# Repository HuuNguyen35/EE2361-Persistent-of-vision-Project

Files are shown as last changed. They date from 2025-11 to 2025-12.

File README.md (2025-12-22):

# EE2361 Persistent-of-Vision (POV) Fan Display  
**EE2361 – Fall 2025 Final Project**

This project implements a **Persistent-of-Vision (POV) display** using a
**PIC24FJ64GA002 microcontroller**, a **DC motor–driven rotating fan**, and a
**WS2812B RGB LED strip** mounted on the fan blade. By synchronizing LED updates
with the fan’s rotation, the system creates the illusion of a stable image or
text in mid-air.

An **IR reflective sensor** measures the fan’s RPM, and an **HTML-based pattern
generator** allows users to design custom RGB patterns that are exported
directly into firmware-ready C arrays.

---

## Demo
https://screenpal.com/content/video/cTl336nY7Au

---

## Key Features
- PIC24FJ64GA002–based embedded control
- 28-LED WS2812B RGB LED strip mounted on a rotating fan blade
- IR sensor–based RPM measurement
- Optional LCD display for live RPM readout
- HTML pixel-art tool to generate POV patterns
- Custom mechanical chassis designed in SolidWorks
- Slip ring used to route power/signals to the rotating blade

---

## System Overview
1. A DC motor spins the fan blade with the LED strip attached.
2. An IR reflective sensor mounted beneath the fan detects each rotation.
3. The PIC24 measures the rotation period and calculates timing for each angular
   column.
4. LED colors are updated at precise times during the rotation.
5. Due to persistence of vision, the viewer perceives a stable image or text.

---

## Hardware
- **Microcontroller:** PIC24FJ64GA002  
- **LEDs:** WS2812B RGB LED strip (28 LEDs total)  
- **Sensor:** TCRT5000 IR reflective sensor module  
- **Motor:** DC motor  
- **Mechanical:**  
  - Custom chassis designed in SolidWorks  
  - Slip ring for rotating electrical connections  
- **Optional:** LCD display for RPM readout  

### Power
- **5 V:** WS2812B LED strip and DC motor  
- **3.3 V:** PIC24FJ64GA002 and IR sensor  
- Power is provided via the **Microchip SNAP board**

---

## Firmware
- **IDE:** MPLAB X  
- **Target MCU:** PIC24FJ64GA002  
- The repository includes a ready-to-build **`.X` MPLAB project**
- No special configuration bits or external libraries required

### Firmware Responsibilities
- Read IR sensor signals to determine rotation timing (RPM)
- Divide each rotation into fixed angular columns
- Output RGB data to the WS2812B LED strip
- Optionally update an LCD with real-time RPM values

---

## Pattern Generator (HTML Tool)
The project includes an HTML-based **circular pixel art generator** used to
design POV display patterns.

### Capabilities
- Paint RGB patterns on a polar grid (radial pixels × angular columns)
- Render text using a built-in 3×5 pixel font
- Export patterns in multiple formats

### Output
- **C source output for PIC24**, including:
  - Pattern dimensions
  - RGB array formatted for direct inclusion in firmware

### How to Use
1. Open the HTML file in a web browser.
2. Create a pattern or render text.
3. Click **Export C (PIC24)**.
4. Copy the generated output into:

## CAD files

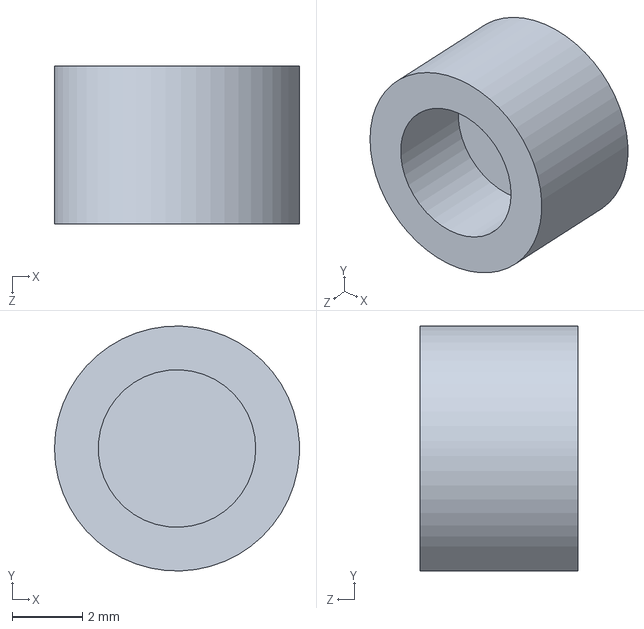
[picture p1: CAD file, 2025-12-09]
EE_2361_pillar_cap.SLDPRT
7.00 x 7.00 x 4.50 mm

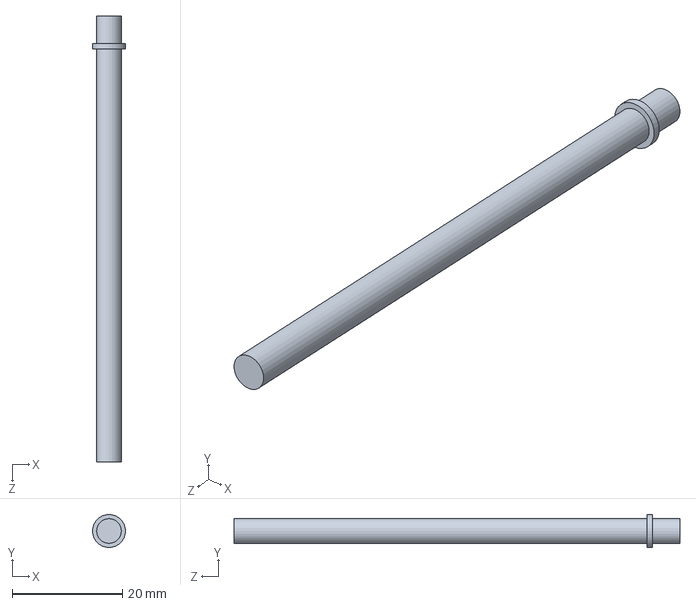
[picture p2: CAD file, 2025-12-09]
EE_2361_pillar.SLDPRT
6.00 x 6.00 x 81.0 mm

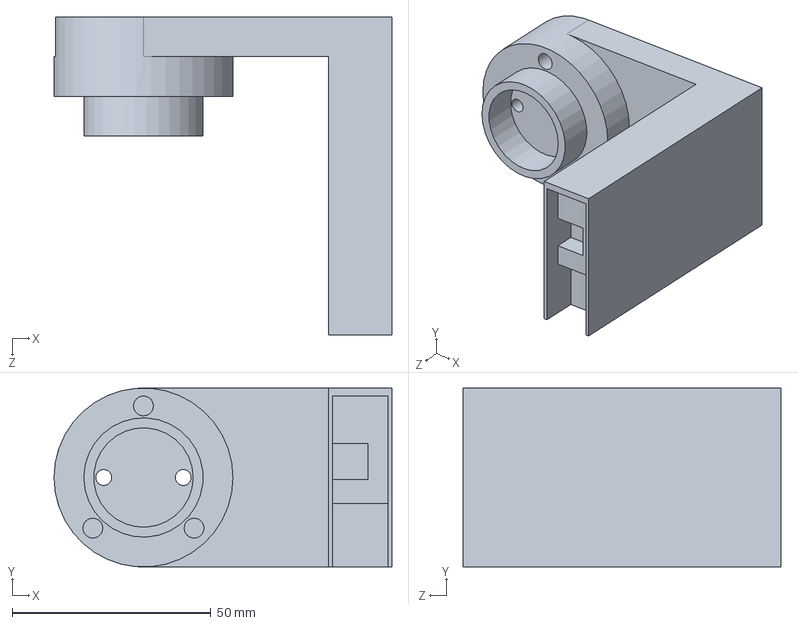
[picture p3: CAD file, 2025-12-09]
EE_2361_fan_holder.SLDPRT
85.0 x 45.0 x 80.0 mm

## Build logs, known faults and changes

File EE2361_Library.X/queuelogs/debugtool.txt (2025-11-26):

753 1764175239638 GEN4_CONNECT_DIAGNOSTICS:MPLABCommTool is NOT null
753 1764175239638 GEN4_CONNECT_DIAGNOSTICS:AttachedToolPID = 9018, AttachedToolVID = 4d8
753 1764175239638 GEN4_CONNECT_DIAGNOSTICS:transport type = USB
753 1764175239639 GEN4_CONNECT_DIAGNOSTICS:AttachedToolPID = 9018, AttachedToolVID = 4d8
753 1764175240054 com.microchip.mplab.mdbcore.RealICETool.RIDbgToolCom
753 1764175240054 GEN4_CONNECT_DIAGNOSTICS:Before MPLABCommTool.Connect()
753 1764175240054 GEN4_CONNECT_DIAGNOSTICS:After MPLABCommTool.Connect()
753 1764175240054 GEN4_CONNECT_DIAGNOSTICS:MPLABCommTool.Connect() returned MPLABCOMM_NO_ERROR
753 1764175240055 GEN4_CONNECT_DIAGNOSTICS:Attaching to MPLABCommTool plugnplay
753 1764175240091 GEN4_CONNECT_DIAGNOSTICS:Adding new plug and play observer com.microchip.mplab.mdbcore.RI4Tool.RI4ToolBase$RI4PlugNPlayObserver@9b9439
753 1764175240091 GEN4_CONNECT_DIAGNOSTICS:Begin PlugNPlayObservers list dump:
753 1764175240091 GEN4_CONNECT_DIAGNOSTICS:com.microchip.mplab.mdbcore.RI4Tool.RI4ToolBase$RI4PlugNPlayObserver@9b9439
753 1764175240091 GEN4_CONNECT_DIAGNOSTICS:End PlugNPlayObservers list dump:
753 1764175240111 GEN4_CONNECT_DIAGNOSTICS:Registering for alternate PNP notifications. CommPnPCriteria.cPIDList = [9019, 901c, 2180], CommPnPCriteria.cSerialNumber = 021038102ryn006859

753 1764175247402 GEN4_TO_CONTROLLER_LOG:GEN4_INIT_INT_LOG_PIC24FJ64GA002 Pre:init
753 1764175247402 GEN4_TO_CONTROLLER_LOG:GEN4_INIT_INT_LOG_PIC24FJ64GA002 Payload
753 1764175247402 GEN4_TO_CONTROLLER_LOG:GEN4_INIT_INT_LOG_PIC24FJ64GA002 DeviceInfo: Values:
753 1764175247402 GEN4_TO_CONTROLLER_LOG:GEN4_INIT_INT_LOG_PIC24FJ64GA002 DeviceInfo: pcAddress = 0000002e, Vpp = 3.25, useRowEraseIfVoltageIsLow = false, voltageBelowWhichUseRowErase = 0.00, deviceName = PIC24FJ64GA002, programmerType = PIC24FJ
753 1764175247402 GEN4_TO_CONTROLLER_LOG:GEN4_INIT_INT_LOG_PIC24FJ64GA002 DeviceInfo: MemInfo values:
753 1764175247404 GEN4_TO_CONTROLLER_LOG:GEN4_INIT_INT_LOG_PIC24FJ64GA002 DeviceInfo: mask = ffffff, exists = true, startAddr = 00000000, endAddr = 0000abfb, rowSize = 0400, rowEraseSize = 0400, addrInc = 0002, widthProgram = 0004
753 1764175247404 GEN4_TO_CONTROLLER_LOG:GEN4_INIT_INT_LOG_PIC24FJ64GA002 DeviceInfo: mask = ffff, exists = true, startAddr = 0000abfc, endAddr = 0000abff, rowSize = 0001, rowEraseSize = 0000, addrInc = 0002, widthProgram = 0002
753 1764175247404 GEN4_TO_CONTROLLER_LOG:GEN4_INIT_INT_LOG_PIC24FJ64GA002 DeviceInfo: mask = 0000, exists = false, startAddr = 00000000, endAddr = 00000000, rowSize = 0000, rowEraseSize = 0400, addrInc = 0000, widthProgram = 0000
753 1764175247404 GEN4_TO_CONTROLLER_LOG:GEN4_INIT_INT_LOG_PIC24FJ64GA002 DeviceInfo: mask = 0000, exists = false, startAddr = 00000000, endAddr = 00000000, rowSize = 0000, rowEraseSize = 0000, addrInc = 0000, widthProgram = 0000
753 1764175247404 GEN4_TO_CONTROLLER_LOG:GEN4_INIT_INT_LOG_PIC24FJ64GA002 DeviceInfo: mask = 0000, exists = false, startAddr = 00000000, endAddr = 00000000, rowSize = 0000, rowEraseSize = 0000, addrInc = 0000, widthProgram = 0000
753 1764175247404 GEN4_TO_CONTROLLER_LOG:GEN4_INIT_INT_LOG_PIC24FJ64GA002 DeviceInfo: mask = ffffff, exists = true, startAddr = 00800000, endAddr = 008007ff, rowSize = 0400, rowEraseSize = 0400, addrInc = 0002, widthProgram = 0004
753 1764175247404 GEN4_TO_CONTROLLER_LOG:GEN4_INIT_INT_LOG_PIC24FJ64GA002 DeviceInfo: mask = 0000, exists = false, startAddr = 00000000, endAddr = 00000000, rowSize = 0000, rowEraseSize = 0000, addrInc = 0002, widthProgram = 0002
753 1764175247404 GEN4_TO_CONTROLLER_LOG:GEN4_INIT_INT_LOG_PIC24FJ64GA002 DeviceInfo: mask = 0000, exists = false, startAddr = 00000000, endAddr = 00000000, rowSize = 0000, rowEraseSize = 0000, addrInc = 0000, widthProgram = 0000
753 1764175247404 GEN4_TO_CONTROLLER_LOG:GEN4_INIT_INT_LOG_PIC24FJ64GA002 DeviceInfo: mask = 0000, exists = false, startAddr = 00000000, endAddr = 00000000, rowSize = 0000, rowEraseSize = 0000, addrInc = 0000, widthProgram = 0000
753 1764175247404 GEN4_TO_CONTROLLER_LOG:GEN4_INIT_INT_LOG_PIC24FJ64GA002 DeviceInfo: mask = 0000, exists = false, startAddr = 00000000, endAddr = 00000000, rowSize = 0000, rowEraseSize = 0000, addrInc = 0000, widthProgram = 0000
753 1764175247404 GEN4_TO_CONTROLLER_LOG:GEN4_INIT_INT_LOG_PIC24FJ64GA002 DeviceInfo: mask = 0000, exists = false, startAddr = 00000000, endAddr = 00000000, rowSize = 0000, rowEraseSize = 0000, addrInc = 0002, widthProgram = 0002
753 1764175247404 GEN4_TO_CONTROLLER_LOG:GEN4_INIT_INT_LOG_PIC24FJ64GA002 DeviceInfo: mask = 0000, exists = false, startAddr = 00000000, endAddr = 00000000, rowSize = 0000, rowEraseSize = 0000, addrInc = 0000, widthProgram = 0000
753 1764175247404 GEN4_TO_CONTROLLER_LOG:GEN4_INIT_INT_LOG_PIC24FJ64GA002 DeviceInfo: mask = 0000, exists = false, startAddr = 00000000, endAddr = 00000000, rowSize = 0000, rowEraseSize = 0000, addrInc = 0000, widthProgram = 0000
753 1764175247404 GEN4_TO_CONTROLLER_LOG:GEN4_INIT_INT_LOG_PIC24FJ64GA002 DeviceInfo: mask = 0000, exists = false, startAddr = 00000000, endAddr = 00000000, rowSize = 0000, rowEraseSize = 0000, addrInc = 0000, widthProgram = 0000
753 1764175247404 GEN4_TO_CONTROLLER_LOG:GEN4_INIT_INT_LOG_PIC24FJ64GA002 DeviceInfo: mask = 0000, exists = false, startAddr = 00000000, endAddr = 00000000, rowSize = 0000, rowEraseSize = 0000, addrInc = 0000, widthProgram = 0000
753 1764175247404 GEN4_TO_CONTROLLER_LOG:GEN4_INIT_INT_LOG_PIC24FJ64GA002 DeviceInfo: mask = 0000, exists = false, startAddr = 00000000, endAddr = 00000000, rowSize = 0000, rowEraseSize = 0000, addrInc = 0000, widthProgram = 0000
753 1764175247404 GEN4_TO_CONTROLLER_LOG:GEN4_INIT_INT_LOG_PIC24FJ64GA002 DeviceInfo: mask = 7fffffff, exists = true, startAddr = 00ff0000, endAddr = 00ff0003, rowSize = 0001, rowEraseSize = 0000, addrInc = 0001, widthProgram = 0001
753 1764175247404 GEN4_TO_CONTROLLER_LOG:GEN4_INIT_INT_LOG_PIC24FJ64GA002 DeviceInfo: mask = 0000, exists = false, startAddr = 00000000, endAddr = 00000000, rowSize = 0000, rowEraseSize = 0000, addrInc = 0000, widthProgram = 0000
753 1764175247404 GEN4_TO_CONTROLLER_LOG:GEN4_INIT_INT_LOG_PIC24FJ64GA002 DeviceInfo: mask = 0000, exists = false, startAddr = 00000000, endAddr = 00000000, rowSize = 0000, rowEraseSize = 0000, addrInc = 0000, widthProgram = 0000
753 1764175247404 GEN4_TO_CONTROLLER_LOG:GEN4_INIT_INT_LOG_PIC24FJ64GA002 DeviceInfo: mask = 0000, exists = false, startAddr = 00000000, endAddr = 00000000, rowSize = 0000, rowEraseSize = 0000, addrInc = 0000, widthProgram = 0000
753 1764175247404 GEN4_TO_CONTROLLER_LOG:GEN4_INIT_INT_LOG_PIC24FJ64GA002 DeviceInfo: mask = 0000, exists = false, startAddr = 00000000, endAddr = 00000000, rowSize = 0000, rowEraseSize = 0000, addrInc = 0000, widthProgram = 0000
753 1764175247404 GEN4_TO_CONTROLLER_LOG:GEN4_INIT_INT_LOG_PIC24FJ64GA002 DeviceInfo: mask = 0000, exists = false, startAddr = 00000000, endAddr = 00000000, rowSize = 0000, rowEraseSize = 0000, addrInc = 0000, widthProgram = 0000
753 1764175247404 GEN4_TO_CONTROLLER_LOG:GEN4_INIT_INT_LOG_PIC24FJ64GA002 DeviceInfo: mask = 0000, exists = false, startAddr = 00000000, endAddr = 00000000, rowSize = 0000, rowEraseSize = 0000, addrInc = 0000, widthProgram = 0000
753 1764175247404 GEN4_TO_CONTROLLER_LOG:GEN4_INIT_INT_LOG_PIC24FJ64GA002 CfgRequiredBitsMask Values:
753 1764175247404 GEN4_TO_CONTROLLER_LOG:GEN4_INIT_INT_LOG_PIC24FJ64GA002 Address = 0000abfc, Mask = 0000fff7
753 1764175247404 GEN4_TO_CONTROLLER_LOG:GEN4_INIT_INT_LOG_PIC24FJ64GA002 Address = 0000abfe, Mask = 000077df
753 1764175247404 GEN4_TO_CONTROLLER_LOG:GEN4_INIT_INT_LOG_PIC24FJ64GA002 BasicInfo: Values:
753 1764175247404 GEN4_TO_CONTROLLER_LOG:GEN4_INIT_INT_LOG_PIC24FJ64GA002 Payload End
753 1764175250065 GEN4_TO_CONTROLLER_LOG:GEN4_INIT_INT_LOG_PIC24FJ64GA002 Post:init
753 1764175250065 GEN4_TO_CONTROLLER_LOG:GEN4_INIT_INT_LOG_PIC24FJ64GA002 Return Value
753 1764175250065 GEN4_TO_CONTROLLER_LOG:GEN4_INIT_INT_LOG_PIC24FJ64GA002 none
753 1764175250065 GEN4_TO_CONTROLLER_LOG:GEN4_INIT_INT_LOG_PIC24FJ64GA002 Return End

753 1764175250066 GEN4_TO_CONTROLLER_LOG:GEN4_INIT_INT_LOG_PIC24FJ64GA002 Pre:GetInterfaceProvider
753 1764175250066 GEN4_TO_CONTROLLER_LOG:GEN4_INIT_INT_LOG_PIC24FJ64GA002 Payload
753 1764175250066 GEN4_TO_CONTROLLER_LOG:GEN4_INIT_INT_LOG_PIC24FJ64GA002 RI4DebugInterface
753 1764175250066 GEN4_TO_CONTROLLER_LOG:GEN4_INIT_INT_LOG_PIC24FJ64GA002 Payload End
753 1764175250066 GEN4_TO_CONTROLLER_LOG:GEN4_INIT_INT_LOG_PIC24FJ64GA002 Post:GetInterfaceProvider
753 1764175250066 GEN4_TO_CONTROLLER_LOG:GEN4_INIT_INT_LOG_PIC24FJ64GA002 Return Value
753 1764175250066 GEN4_TO_CONTROLLER_LOG:GEN4_INIT_INT_LOG_PIC24FJ64GA002 com.microchip.mplab.libs.RI4ToolsController.implementations.RI4DebugInterfaceImpl@4d92831b
753 1764175250066 GEN4_TO_CONTROLLER_LOG:GEN4_INIT_INT_LOG_PIC24FJ64GA002 Return End

753 1764175250198 GEN4_TO_CONTROLLER_LOG:GEN4_INIT_INT_LOG_PIC24FJ64GA002 Pre:GetInterfaceProvider
753 1764175250198 GEN4_TO_CONTROLLER_LOG:GEN4_INIT_INT_LOG_PIC24FJ64GA002 Payload
753 1764175250198 GEN4_TO_CONTROLLER_LOG:GEN4_INIT_INT_LOG_PIC24FJ64GA002 RI4ProgramInterface
753 1764175250198 GEN4_TO_CONTROLLER_LOG:GEN4_INIT_INT_LOG_PIC24FJ64GA002 Payload End
753 1764175250198 GEN4_TO_CONTROLLER_LOG:GEN4_INIT_INT_LOG_PIC24FJ64GA002 Post:GetInterfaceProvider
753 1764175250198 GEN4_TO_CONTROLLER_LOG:GEN4_INIT_INT_LOG_PIC24FJ64GA002 Return Value
753 1764175250198 GEN4_TO_CONTROLLER_LOG:GEN4_INIT_INT_LOG_PIC24FJ64GA002 com.microchip.mplab.libs.RI4ToolsController.implementations.RI4ProgramInterfaceImpl@6d2c703d
753 1764175250198 GEN4_TO_CONTROLLER_LOG:GEN4_INIT_INT_LOG_PIC24FJ64GA002 Return End

753 1764175250281 GEN4_TO_CONTROLLER_LOG:GEN4_INIT_INT_LOG_PIC24FJ64GA002 Pre:GetInterfaceProvider
753 1764175250281 GEN4_TO_CONTROLLER_LOG:GEN4_INIT_INT_LOG_PIC24FJ64GA002 Payload
753 1764175250281 GEN4_TO_CONTROLLER_LOG:GEN4_INIT_INT_LOG_PIC24FJ64GA002 RI4ConnectInterface
753 1764175250281 GEN4_TO_CONTROLLER_LOG:GEN4_INIT_INT_LOG_PIC24FJ64GA002 Payload End
753 1764175250282 GEN4_TO_CONTROLLER_LOG:GEN4_INIT_INT_LOG_PIC24FJ64GA002 Post:GetInterfaceProvider
753 1764175250282 GEN4_TO_CONTROLLER_LOG:GEN4_INIT_INT_LOG_PIC24FJ64GA002 Return Value
753 1764175250282 GEN4_TO_CONTROLLER_LOG:GEN4_INIT_INT_LOG_PIC24FJ64GA002 com.microchip.mplab.libs.PK4ToolsController.PK4ConnectInterfaceImpl@3dc04ec9
753 1764175250282 GEN4_TO_CONTROLLER_LOG:GEN4_INIT_INT_LOG_PIC24FJ64GA002 Return End
753 1764175250329 GEN4_CONNECT_DIAGNOSTICS:acceptablePIDs = [9018, 9019, 901c]
753 1764175250329 GEN4_CONNECT_DIAGNOSTICS:otherPIDs = [2180]
753 1764175250329 GEN4_CONNECT_DIAGNOSTICS:Setting selected tool type to pk4
753 1764175250329 GEN4_CONNECT_DIAGNOSTICS:otherPIDs = [2180]
753 1764175250329 GEN4_CONNECT_DIAGNOSTICS:acceptablePIDs = [9018, 9019, 901c]

753 1764175250332 GEN4_TO_CONTROLLER_LOG:GEN4_CONNECT_INT_LOG_PIC24FJ64GA002 Pre:selectCore
753 1764175250332 GEN4_TO_CONTROLLER_LOG:GEN4_CONNECT_INT_LOG_PIC24FJ64GA002 Payload
753 1764175250332 GEN4_TO_CONTROLLER_LOG:GEN4_CONNECT_INT_LOG_PIC24FJ64GA002 PIC24FJ64GA002
753 1764175250332 GEN4_TO_CONTROLLER_LOG:GEN4_CONNECT_INT_LOG_PIC24FJ64GA002 Payload End
753 1764175250332 GEN4_TO_CONTROLLER_LOG:GEN4_CONNECT_INT_LOG_PIC24FJ64GA002 Post:selectCore
753 1764175250332 GEN4_TO_CONTROLLER_LOG:GEN4_CONNECT_INT_LOG_PIC24FJ64GA002 Return Value
753 1764175250332 GEN4_TO_CONTROLLER_LOG:GEN4_CONNECT_INT_LOG_PIC24FJ64GA002 none
753 1764175250332 GEN4_TO_CONTROLLER_LOG:GEN4_CONNECT_INT_LOG_PIC24FJ64GA002 Return End

753 1764175250332 GEN4_TO_CONTROLLER_LOG:GEN4_INIT_INT_LOG_PIC24FJ64GA002 Pre:GetInterfaceProvider
753 1764175250332 GEN4_TO_CONTROLLER_LOG:GEN4_INIT_INT_LOG_PIC24FJ64GA002 Payload
753 1764175250332 GEN4_TO_CONTROLLER_LOG:GEN4_INIT_INT_LOG_PIC24FJ64GA002 RI4ControllerDiagnosticsInterface
753 1764175250332 GEN4_TO_CONTROLLER_LOG:GEN4_INIT_INT_LOG_PIC24FJ64GA002 Payload End
753 1764175250332 GEN4_TO_CONTROLLER_LOG:GEN4_INIT_INT_LOG_PIC24FJ64GA002 Post:GetInterfaceProvider
753 1764175250332 GEN4_TO_CONTROLLER_LOG:GEN4_INIT_INT_LOG_PIC24FJ64GA002 Return Value
753 1764175250332 GEN4_TO_CONTROLLER_LOG:GEN4_INIT_INT_LOG_PIC24FJ64GA002 com.microchip.mplab.libs.RI4ToolsController.implementations.RI4ControllerDiagnosticsInterfaceImpl@4e9ac538
753 1764175250332 GEN4_TO_CONTROLLER_LOG:GEN4_INIT_INT_LOG_PIC24FJ64GA002 Return End

753 1764175250332 GEN4_TO_CONTROLLER_LOG:GEN4_INIT_INT_LOG_PIC24FJ64GA002 Pre:GetInterfaceProvider
753 1764175250332 GEN4_TO_CONTROLLER_LOG:GEN4_INIT_INT_LOG_PIC24FJ64GA002 Payload
753 1764175250332 GEN4_TO_CONTROLLER_LOG:GEN4_INIT_INT_LOG_PIC24FJ64GA002 ProgrammerToGo
753 1764175250332 GEN4_TO_CONTROLLER_LOG:GEN4_INIT_INT_LOG_PIC24FJ64GA002 Payload End
753 1764175250333 GEN4_TO_CONTROLLER_LOG:GEN4_INIT_INT_LOG_PIC24FJ64GA002 Post:GetInterfaceProvider
753 1764175250333 GEN4_TO_CONTROLLER_LOG:GEN4_INIT_INT_LOG_PIC24FJ64GA002 Return Value
753 1764175250333 GEN4_TO_CONTROLLER_LOG:GEN4_INIT_INT_LOG_PIC24FJ64GA002 com.microchip.mplab.libs.RI4ToolsController.implementations.ProgrammerToGoImpl@c42df67
753 1764175250333 GEN4_TO_CONTROLLER_LOG:GEN4_INIT_INT_LOG_PIC24FJ64GA002 Return End

753 1764175250334 GEN4_TO_CONTROLLER_LOG:GEN4_INIT_INT_LOG_PIC24FJ64GA002 Pre:GetInterfaceProvider
753 1764175250334 GEN4_TO_CONTROLLER_LOG:GEN4_INIT_INT_LOG_PIC24FJ64GA002 Payload
753 1764175250334 GEN4_TO_CONTROLLER_LOG:GEN4_INIT_INT_LOG_PIC24FJ64GA002 Status
753 1764175250334 GEN4_TO_CONTROLLER_LOG:GEN4_INIT_INT_LOG_PIC24FJ64GA002 Payload End
753 1764175250334 GEN4_TO_CONTROLLER_LOG:GEN4_INIT_INT_LOG_PIC24FJ64GA002 Post:GetInterfaceProvider
753 1764175250334 GEN4_TO_CONTROLLER_LOG:GEN4_INIT_INT_LOG_PIC24FJ64GA002 Return Value
753 1764175250334 GEN4_TO_CONTROLLER_LOG:GEN4_INIT_INT_LOG_PIC24FJ64GA002 null
753 1764175250334 GEN4_TO_CONTROLLER_LOG:GEN4_INIT_INT_LOG_PIC24FJ64GA002 Return End

753 1764175250352 GEN4_TO_CONTROLLER_LOG:GEN4_PROGRAM_INT_LOG_PIC24FJ64GA002 Pre:SetProgramExec
753 1764175250352 GEN4_TO_CONTROLLER_LOG:GEN4_PROGRAM_INT_LOG_PIC24FJ64GA002 Payload
753 1764175250354 GEN4_TO_CONTROLLER_LOG:GEN4_PROGRAM_INT_LOG_PIC24FJ64GA002 Test
753 1764175250354 GEN4_TO_CONTROLLER_LOG:GEN4_PROGRAM_INT_LOG_PIC24FJ64GA002 800000
753 1764175250354 GEN4_TO_CONTROLLER_LOG:GEN4_PROGRAM_INT_LOG_PIC24FJ64GA002 Length = 3054
753 1764175250354 GEN4_TO_CONTROLLER_LOG:GEN4_PROGRAM_INT_LOG_PIC24FJ64GA002 Payload End
753 1764175250355 GEN4_TO_CONTROLLER_LOG:GEN4_PROGRAM_INT_LOG_PIC24FJ64GA002 Post:SetProgramExec
753 1764175250355 GEN4_TO_CONTROLLER_LOG:GEN4_PROGRAM_INT_LOG_PIC24FJ64GA002 Return Value
753 1764175250355 GEN4_TO_CONTROLLER_LOG:GEN4_PROGRAM_INT_LOG_PIC24FJ64GA002 true
753 1764175250355 GEN4_TO_CONTROLLER_LOG:GEN4_PROGRAM_INT_LOG_PIC24FJ64GA002 Return End
753 1764175250355 GEN4_CONNECT_DIAGNOSTICS:ENTERING: com.microchip.mplab.mdbcore.RI4Tool.ConnectionHandler.CheckForFWUpdates()
753 1764175250355 GEN4_CONNECT_DIAGNOSTICS:Created FirmwareUpdateHandler com.microchip.mplab.mdbcore.pk4hybrid.pk4hybridFirmwareUpdateHandler@5181b78c
753 1764175250355 GEN4_CONNECT_DIAGNOSTICS:ENTERING: com.microchip.mplab.mdbcore.pk4hybrid.pk4hybridFirmwareUpdateHandler.UpdateFirmware(FirmwareInfo, UpdateMessage)
753 1764175250358 GEN4_CONNECT_DIAGNOSTICS:areWeInBoot returned false
753 1764175250358 GEN4_CONNECT_DIAGNOSTICS:inBoot = false
753 1764175250358 GEN4_CONNECT_DIAGNOSTICS:uMode = checkingVersions
753 1764175250358 GEN4_CONNECT_DIAGNOSTICS:selectedTool = pk4
753 1764175250358 GEN4_CONNECT_DIAGNOSTICS:current toolType = pk4
753 1764175250358 GEN4_CONNECT_DIAGNOSTICS:current tool mode = pk4
753 1764175250358 GEN4_CONNECT_DIAGNOSTICS:ENTERING: com.microchip.mplab.mdbcore.pk4hybrid.pk4hybridFirmwareUpdateHandler.GetUpdateInfo()
753 1764175250415 GEN4_CONNECT_DIAGNOSTICS:Parsing file  for firmware updates
753 1764175250415 GEN4_CONNECT_DIAGNOSTICS:ENTERING: com.microchip.mplab.mdbcore.pk4hybrid.pk4hybridFirmwareUpdateHandler.ParseSelectedVersionsFromJamFile()
753 1764175250415 GEN4_CONNECT_DIAGNOSTICS:Jame file line = snap_boot.hex,010155
753 1764175250415 GEN4_CONNECT_DIAGNOSTICS:Jame file line = scripts.xml,000891
753 1764175250415 GEN4_CONNECT_DIAGNOSTICS:Jame file line = snap_app1 020338, 0040C000
753 1764175250415 GEN4_CONNECT_DIAGNOSTICS:Jame file line = snap_app2 1.11.20, 00500000
753 1764175250415 GEN4_CONNECT_DIAGNOSTICS:Jame file line = snap_app3 000000, FFFFFFFF
753 1764175250415 GEN4_CONNECT_DIAGNOSTICS:Jame file line = snap_app4 000000, FFFFFFFF
753 1764175250415 GEN4_CONNECT_DIAGNOSTICS:Jame file line = snap_app5 000000, FFFFFFFF
753 1764175250415 GEN4_CONNECT_DIAGNOSTICS:Jame file line = snap_app6 000000, FFFFFFFF
753 1764175250415 GEN4_CONNECT_DIAGNOSTICS:Jame file line = snap_app7 000000, FFFFFFFF
753 1764175250415 GEN4_CONNECT_DIAGNOSTICS:Jame file line = snap_app8 000000, FFFFFFFF
753 1764175250415 GEN4_CONNECT_DIAGNOSTICS:EXITING: com.microchip.mplab.mdbcore.pk4hybrid.pk4hybridFirmwareUpdateHandler.ri4ParseSelectedVersionsFromJamFile()
753 1764175250415 GEN4_CONNECT_DIAGNOSTICS:EXITING: com.microchip.mplab.mdbcore.pk4hybrid.pk4hybridFirmwareUpdateHandler.GetUpdateInfo()
753 1764175250415 GEN4_CONNECT_DIAGNOSTICS:current toolType = pk4

753 1764175250415 GEN4_TO_CONTROLLER_LOG:GEN4_CONNECT_INT_LOG_PIC24FJ64GA002 Pre:EstablishCommunincations
753 1764175250415 GEN4_TO_CONTROLLER_LOG:GEN4_CONNECT_INT_LOG_PIC24FJ64GA002 Payload
753 1764175250415 GEN4_TO_CONTROLLER_LOG:GEN4_CONNECT_INT_LOG_PIC24FJ64GA002 com.microchip.mplab.mdbcore.PK4Tool.PK4Com@91e7ac0
753 1764175250415 GEN4_TO_CONTROLLER_LOG:GEN4_CONNECT_INT_LOG_PIC24FJ64GA002 Payload End
753 1764175250423 GEN4_TO_CONTROLLER_LOG:GEN4_CONNECT_INT_LOG_PIC24FJ64GA002 Post:EstablishCommunincations
753 1764175250423 GEN4_TO_CONTROLLER_LOG:GEN4_CONNECT_INT_LOG_PIC24FJ64GA002 Return Value
753 1764175250423 GEN4_TO_CONTROLLER_LOG:GEN4_CONNECT_INT_LOG_PIC24FJ64GA002 true
753 1764175250423 GEN4_TO_CONTROLLER_LOG:GEN4_CONNECT_INT_LOG_PIC24FJ64GA002 Return End

753 1764175250423 GEN4_TO_CONTROLLER_LOG:GEN4_CONNECT_INT_LOG_PIC24FJ64GA002 Pre:GetFirmwareInfo
753 1764175250423 GEN4_TO_CONTROLLER_LOG:GEN4_CONNECT_INT_LOG_PIC24FJ64GA002 Payload
753 1764175250423 GEN4_TO_CONTROLLER_LOG:GEN4_CONNECT_INT_LOG_PIC24FJ64GA002 null
753 1764175250423 GEN4_TO_CONTROLLER_LOG:GEN4_CONNECT_INT_LOG_PIC24FJ64GA002 Payload End
753 1764175250433 GEN4_TO_CONTROLLER_LOG:GEN4_CONNECT_INT_LOG_PIC24FJ64GA002 Post:GetFirmwareInfo
753 1764175250433 GEN4_TO_CONTROLLER_LOG:GEN4_CONNECT_INT_LOG_PIC24FJ64GA002 Return Value
753 1764175250433 GEN4_TO_CONTROLLER_LOG:GEN4_CONNECT_INT_LOG_PIC24FJ64GA002 FirmwareInfo: Values:
753 1764175250434 GEN4_TO_CONTROLLER_LOG:GEN4_CONNECT_INT_LOG_PIC24FJ64GA002 FirmwareInfo: boot = false, bootVer = 01.01.55, apVer = 02.03.38, fpgaVer = ff.ff.ff, scriptVer = 00.08.91, macAddress = 0495683578451535052485353485350, devID = a1020e01, devID1 = 1, devSN0 = ffffffff, devSN1 = ffffffff, serialNumber = 021038102RYN006859, appCommitID = null, scriptCommitID = 0674c1b56b, PCB_ID = 2
753 1764175250434 GEN4_TO_CONTROLLER_LOG:GEN4_CONNECT_INT_LOG_PIC24FJ64GA002 Return End
753 1764175250439 GEN4_CONNECT_DIAGNOSTICS:appNeedsUpdate returned false
753 1764175250439 GEN4_CONNECT_DIAGNOSTICS:EXITING: com.microchip.mplab.mdbcore.RI4Tool.ConnectionHandler.CheckForFWUpdates()

753 1764175250440 GEN4_TO_CONTROLLER_LOG:GEN4_CONNECT_INT_LOG_PIC24FJ64GA002 Pre:EstablishCommunincations
753 1764175250440 GEN4_TO_CONTROLLER_LOG:GEN4_CONNECT_INT_LOG_PIC24FJ64GA002 Payload
753 1764175250440 GEN4_TO_CONTROLLER_LOG:GEN4_CONNECT_INT_LOG_PIC24FJ64GA002 com.microchip.mplab.mdbcore.PK4Tool.PK4Com@91e7ac0
753 1764175250440 GEN4_TO_CONTROLLER_LOG:GEN4_CONNECT_INT_LOG_PIC24FJ64GA002 Payload End
753 1764175250440 GEN4_TO_CONTROLLER_LOG:GEN4_CONNECT_INT_LOG_PIC24FJ64GA002 Post:EstablishCommunincations
753 1764175250440 GEN4_TO_CONTROLLER_LOG:GEN4_CONNECT_INT_LOG_PIC24FJ64GA002 Return Value
753 1764175250440 GEN4_TO_CONTROLLER_LOG:GEN4_CONNECT_INT_LOG_PIC24FJ64GA002 true
753 1764175250440 GEN4_TO_CONTROLLER_LOG:GEN4_CONNECT_INT_LOG_PIC24FJ64GA002 Return End

753 1764175250440 GEN4_TO_CONTROLLER_LOG:GEN4_CONNECT_INT_LOG_PIC24FJ64GA002 Pre:GetFirmwareInfo
753 1764175250440 GEN4_TO_CONTROLLER_LOG:GEN4_CONNECT_INT_LOG_PIC24FJ64GA002 Payload
753 1764175250440 GEN4_TO_CONTROLLER_LOG:GEN4_CONNECT_INT_LOG_PIC24FJ64GA002 null
753 1764175250440 GEN4_TO_CONTROLLER_LOG:GEN4_CONNECT_INT_LOG_PIC24FJ64GA002 Payload End
753 1764175250448 GEN4_TO_CONTROLLER_LOG:GEN4_CONNECT_INT_LOG_PIC24FJ64GA002 Post:GetFirmwareInfo
753 1764175250448 GEN4_TO_CONTROLLER_LOG:GEN4_CONNECT_INT_LOG_PIC24FJ64GA002 Return Value
753 1764175250448 GEN4_TO_CONTROLLER_LOG:GEN4_CONNECT_INT_LOG_PIC24FJ64GA002 FirmwareInfo: Values:
753 1764175250448 GEN4_TO_CONTROLLER_LOG:GEN4_CONNECT_INT_LOG_PIC24FJ64GA002 FirmwareInfo: boot = false, bootVer = 01.01.55, apVer = 02.03.38, fpgaVer = ff.ff.ff, scriptVer = 00.08.91, macAddress = 0495683578451535052485353485350, devID = a1020e01, devID1 = 1, devSN0 = ffffffff, devSN1 = ffffffff, serialNumber = 021038102RYN006859, appCommitID = null, scriptCommitID = 0674c1b56b, PCB_ID = 2
753 1764175250448 GEN4_TO_CONTROLLER_LOG:GEN4_CONNECT_INT_LOG_PIC24FJ64GA002 Return End

753 1764175250449 GEN4_TO_CONTROLLER_LOG:GEN4_CONNECT_INT_LOG_PIC24FJ64GA002 Pre:GetFirmwareInfo
753 1764175250449 GEN4_TO_CONTROLLER_LOG:GEN4_CONNECT_INT_LOG_PIC24FJ64GA002 Payload
753 1764175250449 GEN4_TO_CONTROLLER_LOG:GEN4_CONNECT_INT_LOG_PIC24FJ64GA002 null
753 1764175250449 GEN4_TO_CONTROLLER_LOG:GEN4_CONNECT_INT_LOG_PIC24FJ64GA002 Payload End
753 1764175250456 GEN4_TO_CONTROLLER_LOG:GEN4_CONNECT_INT_LOG_PIC24FJ64GA002 Post:GetFirmwareInfo
753 1764175250456 GEN4_TO_CONTROLLER_LOG:GEN4_CONNECT_INT_LOG_PIC24FJ64GA002 Return Value
753 1764175250456 GEN4_TO_CONTROLLER_LOG:GEN4_CONNECT_INT_LOG_PIC24FJ64GA002 FirmwareInfo: Values:
753 1764175250456 GEN4_TO_CONTROLLER_LOG:GEN4_CONNECT_INT_LOG_PIC24FJ64GA002 FirmwareInfo: boot = false, bootVer = 01.01.55, apVer = 02.03.38, fpgaVer = ff.ff.ff, scriptVer = 00.08.91, macAddress = 0495683578451535052485353485350, devID = a1020e01, devID1 = 1, devSN0 = ffffffff, devSN1 = ffffffff, serialNumber = 021038102RYN006859, appCommitID = null, scriptCommitID = 0674c1b56b, PCB_ID = 2
753 1764175250456 GEN4_TO_CONTROLLER_LOG:GEN4_CONNECT_INT_LOG_PIC24FJ64GA002 Return End
753 1764175250459 GEN4_CONNECT_DIAGNOSTICS:ENTERING: com.microchip.mplab.mdbcore.RI4Tool.ConnectionHandler.CheckForFWUpdates()
753 1764175250459 GEN4_CONNECT_DIAGNOSTICS:Created FirmwareUpdateHandler com.microchip.mplab.mdbcore.pk4hybrid.pk4hybridFirmwareUpdateHandler@5181b78c
753 1764175250459 GEN4_CONNECT_DIAGNOSTICS:ENTERING: com.microchip.mplab.mdbcore.pk4hybrid.pk4hybridFirmwareUpdateHandler.UpdateFirmware(FirmwareInfo, UpdateMessage)
753 1764175250459 GEN4_CONNECT_DIAGNOSTICS:areWeInBoot returned false
753 1764175250459 GEN4_CONNECT_DIAGNOSTICS:inBoot = false
753 1764175250459 GEN4_CONNECT_DIAGNOSTICS:uMode = done
753 1764175250459 GEN4_CONNECT_DIAGNOSTICS:selectedTool = pk4
753 1764175250459 GEN4_CONNECT_DIAGNOSTICS:current toolType = pk4
753 1764175250459 GEN4_CONNECT_DIAGNOSTICS:current tool mode = pk4
753 1764175250459 GEN4_CONNECT_DIAGNOSTICS:ENTERING: com.microchip.mplab.mdbcore.pk4hybrid.pk4hybridFirmwareUpdateHandler.updatePk4HybridFirmware()
753 1764175250459 GEN4_CONNECT_DIAGNOSTICS:Don't upgrade fimware = false
753 1764175250459 GEN4_CONNECT_DIAGNOSTICS:ENTERING: com.microchip.mplab.mdbcore.pk4hybrid.pk4hybridFirmwareUpdateHandler.updatePk4HybridFirmware()
753 1764175250459 GEN4_CONNECT_DIAGNOSTICS:EXITING: com.microchip.mplab.mdbcore.pk4hybrid.pk4hybridFirmwareUpdateHandler.UpdateFirmware(FirmwareInfo, UpdateMessage)
753 1764175250459 GEN4_CONNECT_DIAGNOSTICS:EXITING: com.microchip.mplab.mdbcore.RI4Tool.ConnectionHandler.CheckForFWUpdates()

753 1764175250460 GEN4_TO_CONTROLLER_LOG:GEN4_CONNECT_INT_LOG_PIC24FJ64GA002 Pre:SetPowerInfo
753 1764175250460 GEN4_TO_CONTROLLER_LOG:GEN4_CONNECT_INT_LOG_PIC24FJ64GA002 Payload
753 1764175250460 GEN4_TO_CONTROLLER_LOG:GEN4_CONNECT_INT_LOG_PIC24FJ64GA002 PowerInfo: Values:
753 1764175250460 GEN4_TO_CONTROLLER_LOG:GEN4_CONNECT_INT_LOG_PIC24FJ64GA002 PowerInfo: shotDownSystem = false, isToolPower = false, voltage = 3.300000, useVppFirst = false, useLowVoltageProgramming = true, useMaintainActivePower = false
753 1764175250460 GEN4_TO_CONTROLLER_LOG:GEN4_CONNECT_INT_LOG_PIC24FJ64GA002 Payload End
753 1764175250460 XXXX 1764175250460, Thread 753: XXXX 1764175250460, Entering Thread 753: Commands::runScriptBasic with script contents. contents[0] = 0x39, ...  
753 1764175250464 XXXX 1764175250464, Thread 753: XXXX 1764175250464, Exiting Thread 753: Commands::runScriptBasic  
753 1764175250464 XXXX 1764175250464, Thread 753: XXXX 1764175250464, Entering Thread 753: Commands::runScriptBasic with script contents. contents[0] = 0x46, ...  
753 1764175250464 XXXX 1764175250464, Thread 753: XXXX 1764175250464, Exiting Thread 753: Commands::runScriptBasic  
753 1764175250464 XXXX 1764175250464, Thread 753: XXXX 1764175250464, Entering Thread 753: Commands::runScriptBasic with script contents. contents[0] = 0x44, ...  
753 1764175250465 XXXX 1764175250465, Thread 753: XXXX 1764175250465, Exiting Thread 753: Commands::runScriptBasic  
753 1764175250465 XXXX 1764175250465, Thread 753: XXXX 1764175250465, Entering Thread 753: Commands::runScriptBasic with script contents. contents[0] = 0xef, ...  
753 1764175250466 XXXX 1764175250466, Thread 753: XXXX 1764175250466, Exiting Thread 753: Commands::runScriptBasic  
753 1764175250466 XXXX 1764175250466, Thread 753: XXXX 1764175250466, Entering Thread 753: Commands::runScriptBasic with script contents. contents[0] = 0x40, ...  
753 1764175250467 XXXX 1764175250467, Thread 753: XXXX 1764175250467, Exiting Thread 753: Commands::runScriptBasic  
753 1764175250467 XXXX 1764175250467, Thread 753: XXXX 1764175250467, Entering Thread 753: Commands::runScriptBasic with script contents. contents[0] = 0x47, ...  
753 1764175250468 XXXX 1764175250468, Thread 753: XXXX 1764175250468, Exiting Thread 753: Commands::runScriptBasic  
753 1764175250468 GEN4_TO_CONTROLLER_LOG:GEN4_CONNECT_INT_LOG_PIC24FJ64GA002 Post:SetPowerInfo
753 1764175250468 GEN4_TO_CONTROLLER_LOG:GEN4_CONNECT_INT_LOG_PIC24FJ64GA002 Return Value
753 1764175250468 GEN4_TO_CONTROLLER_LOG:GEN4_CONNECT_INT_LOG_PIC24FJ64GA002 none
753 1764175250468 GEN4_TO_CONTROLLER_LOG:GEN4_CONNECT_INT_LOG_PIC24FJ64GA002 Return End

753 1764175250468 GEN4_TO_CONTROLLER_LOG:GEN4_CONNECT_INT_LOG_PIC24FJ64GA002 Pre:GetVoltageInfo
753 1764175250468 GEN4_TO_CONTROLLER_LOG:GEN4_CONNECT_INT_LOG_PIC24FJ64GA002 Payload
753 1764175250468 GEN4_TO_CONTROLLER_LOG:GEN4_CONNECT_INT_LOG_PIC24FJ64GA002 null
753 1764175250468 GEN4_TO_CONTROLLER_LOG:GEN4_CONNECT_INT_LOG_PIC24FJ64GA002 Payload End
753 1764175250468 XXXX 1764175250468, Thread 753: XXXX 1764175250468, Entering Thread 753: Commands::runScriptBasic with script contents. contents[0] = 0x47, ...  
753 1764175250469 XXXX 1764175250469, Thread 753: XXXX 1764175250469, Exiting Thread 753: Commands::runScriptBasic  
753 1764175250469 GEN4_TO_CONTROLLER_LOG:GEN4_CONNECT_INT_LOG_PIC24FJ64GA002 Post:GetVoltageInfo
753 1764175250469 GEN4_TO_CONTROLLER_LOG:GEN4_CONNECT_INT_LOG_PIC24FJ64GA002 Return Value
753 1764175250469 GEN4_TO_CONTROLLER_LOG:GEN4_CONNECT_INT_LOG_PIC24FJ64GA002 VoltagesInfo: Values:
753 1764175250469 GEN4_TO_CONTROLLER_LOG:GEN4_CONNECT_INT_LOG_PIC24FJ64GA002 VoltagesInfo: internalVdd = 3300, internalVpp = 3300, targetVdd = 3300, targetVpp = 3300, vddSense = 3300, temp = 25000, vddCurrentSense = 0, vddVoltageSense = 3300
753 1764175250469 GEN4_TO_CONTROLLER_LOG:GEN4_CONNECT_INT_LOG_PIC24FJ64GA002 Return End

753 1764175250469 GEN4_TO_CONTROLLER_LOG:GEN4_CONNECT_INT_LOG_PIC24FJ64GA002 Pre:GetFirmwareInfo
753 1764175250469 GEN4_TO_CONTROLLER_LOG:GEN4_CONNECT_INT_LOG_PIC24FJ64GA002 Payload
753 1764175250469 GEN4_TO_CONTROLLER_LOG:GEN4_CONNECT_INT_LOG_PIC24FJ64GA002 null
753 1764175250469 GEN4_TO_CONTROLLER_LOG:GEN4_CONNECT_INT_LOG_PIC24FJ64GA002 Payload End
753 1764175250477 GEN4_TO_CONTROLLER_LOG:GEN4_CONNECT_INT_LOG_PIC24FJ64GA002 Post:GetFirmwareInfo
753 1764175250477 GEN4_TO_CONTROLLER_LOG:GEN4_CONNECT_INT_LOG_PIC24FJ64GA002 Return Value
753 1764175250477 GEN4_TO_CONTROLLER_LOG:GEN4_CONNECT_INT_LOG_PIC24FJ64GA002 FirmwareInfo: Values:
753 1764175250477 GEN4_TO_CONTROLLER_LOG:GEN4_CONNECT_INT_LOG_PIC24FJ64GA002 FirmwareInfo: boot = false, bootVer = 01.01.55, apVer = 02.03.38, fpgaVer = ff.ff.ff, scriptVer = 00.08.91, macAddress = 0495683578451535052485353485350, devID = a1020e01, devID1 = 1, devSN0 = ffffffff, devSN1 = ffffffff, serialNumber = 021038102RYN006859, appCommitID = null, scriptCommitID = 0674c1b56b, PCB_ID = 2
753 1764175250477 GEN4_TO_CONTROLLER_LOG:GEN4_CONNECT_INT_LOG_PIC24FJ64GA002 Return End

753 1764175250477 GEN4_TO_CONTROLLER_LOG:GEN4_CONNECT_INT_LOG_PIC24FJ64GA002 Pre:SetToolInfo
753 1764175250477 GEN4_TO_CONTROLLER_LOG:GEN4_CONNECT_INT_LOG_PIC24FJ64GA002 Payload
753 1764175250477 GEN4_TO_CONTROLLER_LOG:GEN4_CONNECT_INT_LOG_PIC24FJ64GA002 ToolInfo: Values:
753 1764175250477 GEN4_TO_CONTROLLER_LOG:GEN4_CONNECT_INT_LOG_PIC24FJ64GA002 ToolInfo: speedLevel = 1, PGCResistance = 4700, PGDResistance = 4700, PGCPullDir = PullDown, PGDPullDir = PullDown, ICSPSelected = Wire2
753 1764175250477 GEN4_TO_CONTROLLER_LOG:GEN4_CONNECT_INT_LOG_PIC24FJ64GA002 Payload End
753 1764175250477 XXXX 1764175250477, Thread 753: XXXX 1764175250477, Entering Thread 753: Commands::runScriptBasic with script contents. contents[0] = 0x27, ...  
753 1764175250478 XXXX 1764175250478, Thread 753: XXXX 1764175250478, Exiting Thread 753: Commands::runScriptBasic  
753 1764175250478 XXXX 1764175250478, Thread 753: XXXX 1764175250478, Entering Thread 753: Commands::runScriptBasic, script name = SetSpeedFromDevice, timeOut = -1 ms  
753 1764175250479 XXXX 1764175250479, Thread 753: XXXX 1764175250479, Exiting Thread 753: Commands::runScriptBasic  
753 1764175250479 XXXX 1764175250479, Thread 753: XXXX 1764175250479, Entering Thread 753: Commands::runScriptBasic with script contents. contents[0] = 0xed, ...  
753 1764175250480 XXXX 1764175250480, Thread 753: XXXX 1764175250480, Exiting Thread 753: Commands::runScriptBasic  
753 1764175250480 XXXX 1764175250480, Thread 753: XXXX 1764175250480, Entering Thread 753: Commands::runScriptBasic with script contents. contents[0] = 0xec, ...  
753 1764175250481 XXXX 1764175250481, Thread 753: XXXX 1764175250481, Exiting Thread 753: Commands::runScriptBasic  
753 1764175250481 XXXX 1764175250481, Thread 753: XXXX 1764175250481, Entering Thread 753: Commands::runScriptBasic with script contents. contents[0] = 0xd4, ...  
753 1764175250482 XXXX 1764175250482, Thread 753: XXXX 1764175250482, Exiting Thread 753: Commands::runScriptBasic  
753 1764175250482 XXXX 1764175250482, Thread 753: XXXX 1764175250482, Entering Thread 753: Commands::runScriptBasic with script contents. contents[0] = 0xcd, ...  
753 1764175250483 XXXX 1764175250483, Thread 753: XXXX 1764175250483, Exiting Thread 753: Commands::runScriptBasic  
753 1764175250483 XXXX 1764175250483, Thread 753: XXXX 1764175250483, Entering Thread 753: Commands::runScriptBasic with script contents. contents[0] = 0xce, ...  
753 1764175250484 XXXX 1764175250484, Thread 753: XXXX 1764175250484, Exiting Thread 753: Commands::runScriptBasic  
753 1764175250484 XXXX 1764175250484, Thread 753: XXXX 1764175250484, Entering Thread 753: Commands::runScriptBasic with script contents. contents[0] = 0xcd, ...  
753 1764175250485 XXXX 1764175250485, Thread 753: XXXX 1764175250485, Exiting Thread 753: Commands::runScriptBasic  
753 1764175250485 XXXX 1764175250485, Thread 753: XXXX 1764175250485, Entering Thread 753: Commands::runScriptBasic with script contents. contents[0] = 0xce, ...  
753 1764175250486 XXXX 1764175250486, Thread 753: XXXX 1764175250486, Exiting Thread 753: Commands::runScriptBasic  
753 1764175250486 GEN4_TO_CONTROLLER_LOG:GEN4_CONNECT_INT_LOG_PIC24FJ64GA002 Post:SetToolInfo
753 1764175250486 GEN4_TO_CONTROLLER_LOG:GEN4_CONNECT_INT_LOG_PIC24FJ64GA002 Return Value
753 1764175250486 GEN4_TO_CONTROLLER_LOG:GEN4_CONNECT_INT_LOG_PIC24FJ64GA002 none
753 1764175250486 GEN4_TO_CONTROLLER_LOG:GEN4_CONNECT_INT_LOG_PIC24FJ64GA002 Return End

753 1764175250487 GEN4_TO_CONTROLLER_LOG:GEN4_CONNECT_INT_LOG_PIC24FJ64GA002 Pre:GetTargetIDInfo
753 1764175250487 GEN4_TO_CONTROLLER_LOG:GEN4_CONNECT_INT_LOG_PIC24FJ64GA002 Payload
753 1764175250487 GEN4_TO_CONTROLLER_LOG:GEN4_CONNECT_INT_LOG_PIC24FJ64GA002 null
753 1764175250487 GEN4_TO_CONTROLLER_LOG:GEN4_CONNECT_INT_LOG_PIC24FJ64GA002 Payload End
753 1764175250489 XXXX 1764175250489, Thread 753: XXXX 1764175250489, Entering Thread 753: Commands::runScriptBasic, script name = SetSpeedFromDevice, timeOut = -1 ms  
753 1764175250490 XXXX 1764175250490, Thread 753: XXXX 1764175250490, Exiting Thread 753: Commands::runScriptBasic  
753 1764175250490 XXXX 1764175250490, Thread 753: XXXX 1764175250490, Entering Thread 753: Commands::runScriptBasic with script contents. contents[0] = 0xed, ...  
753 1764175250491 XXXX 1764175250491, Thread 753: XXXX 1764175250491, Exiting Thread 753: Commands::runScriptBasic  
753 1764175250491 XXXX 1764175250491, Thread 753: XXXX 1764175250491, Entering Thread 753: Commands::runScriptBasic with script contents. contents[0] = 0xec, ...  
753 1764175250492 XXXX 1764175250492, Thread 753: XXXX 1764175250492, Exiting Thread 753: Commands::runScriptBasic  
753 1764175250492 XXXX 1764175250492, Thread 753: XXXX 1764175250492, Entering Thread 753: Commands::runScriptBasic, script name = EnterTMOD_LV, timeOut = -1 ms  
753 1764175250520 XXXX 1764175250520, Thread 753: XXXX 1764175250520, Exiting Thread 753: Commands::runScriptBasic  
753 1764175250520 XXXX 1764175250520, Thread 753: XXXX 1764175250520, Entering Thread 753: Commands::runScriptBasic, script name = GetDeviceID, timeOut = -1 ms  
753 1764175250522 XXXX 1764175250522, Thread 753: XXXX 1764175250522, Exiting Thread 753: Commands::runScriptBasic  
753 1764175250522 GEN4_TO_CONTROLLER_LOG:GEN4_CONNECT_INT_LOG_PIC24FJ64GA002 Post:GetTargetIDInfo
753 1764175250522 GEN4_TO_CONTROLLER_LOG:GEN4_CONNECT_INT_LOG_PIC24FJ64GA002 Return Value
753 1764175250522 GEN4_TO_CONTROLLER_LOG:GEN4_CONNECT_INT_LOG_PIC24FJ64GA002 TargetIDInfo: Values:
753 1764175250522 GEN4_TO_CONTROLLER_LOG:GEN4_CONNECT_INT_LOG_PIC24FJ64GA002 TargetIDInfo: DeviceID = 04473046
753 1764175250522 GEN4_TO_CONTROLLER_LOG:GEN4_CONNECT_INT_LOG_PIC24FJ64GA002 Return End

753 1764175250633 GEN4_TO_CONTROLLER_LOG:GEN4_PROGRAM_INT_LOG_PIC24FJ64GA002 Pre:SendOperation
753 1764175250633 GEN4_TO_CONTROLLER_LOG:GEN4_PROGRAM_INT_LOG_PIC24FJ64GA002 Payload
753 1764175250633 GEN4_TO_CONTROLLER_LOG:GEN4_PROGRAM_INT_LOG_PIC24FJ64GA002 OperationInfo: Values:
753 1764175250633 GEN4_TO_CONTROLLER_LOG:GEN4_PROGRAM_INT_LOG_PIC24FJ64GA002 OperationInfo: Type = erase, Mask = 00000000, Erase = false, Production Mode = true
753 1764175250633 GEN4_TO_CONTROLLER_LOG:GEN4_PROGRAM_INT_LOG_PIC24FJ64GA002 TransferInfo: Start = 0, End = abfb, Buffer Length = 0, Type = Pgm, Mask = 00000000
753 1764175250633 GEN4_TO_CONTROLLER_LOG:GEN4_PROGRAM_INT_LOG_PIC24FJ64GA002 TransferInfo: Start = abfc, End = abff, Buffer Length = 0, Type = Cfg, Mask = 00000000
753 1764175250633 GEN4_TO_CONTROLLER_LOG:GEN4_PROGRAM_INT_LOG_PIC24FJ64GA002 Payload End
753 1764175250633 XXXX 1764175250633, Thread 753: XXXX 1764175250633, Entering Thread 753: Commands::runScriptBasic, script name = EraseChip, timeOut = 30000 ms  
753 1764175250847 XXXX 1764175250847, Thread 753: XXXX 1764175250847, Exiting Thread 753: Commands::runScriptBasic  
753 1764175250947 XXXX 1764175250947, Thread 753: XXXX 1764175250947, Entering Thread 753: Commands::runScriptBasic, script name = ExitTMOD, timeOut = -1 ms  
753 1764175250950 XXXX 1764175250950, Thread 753: XXXX 1764175250950, Exiting Thread 753: Commands::runScriptBasic  
753 1764175250950 GEN4_TO_CONTROLLER_LOG:GEN4_PROGRAM_INT_LOG_PIC24FJ64GA002 Post:SendOperation
753 1764175250950 GEN4_TO_CONTROLLER_LOG:GEN4_PROGRAM_INT_LOG_PIC24FJ64GA002 Return Value
753 1764175250950 GEN4_TO_CONTROLLER_LOG:GEN4_PROGRAM_INT_LOG_PIC24FJ64GA002 None
753 1764175250950 GEN4_TO_CONTROLLER_LOG:GEN4_PROGRAM_INT_LOG_PIC24FJ64GA002 Return End

753 1764175250965 GEN4_TO_CONTROLLER_LOG:GEN4_PROGRAM_INT_LOG_PIC24FJ64GA002 Pre:SendOperation
753 1764175250965 GEN4_TO_CONTROLLER_LOG:GEN4_PROGRAM_INT_LOG_PIC24FJ64GA002 Payload
753 1764175250965 GEN4_TO_CONTROLLER_LOG:GEN4_PROGRAM_INT_LOG_PIC24FJ64GA002 OperationInfo: Values:
753 1764175250965 GEN4_TO_CONTROLLER_LOG:GEN4_PROGRAM_INT_LOG_PIC24FJ64GA002 OperationInfo: Type = read, Mask = 00000000, Erase = false, Production Mode = true
753 1764175250965 GEN4_TO_CONTROLLER_LOG:GEN4_PROGRAM_INT_LOG_PIC24FJ64GA002 TransferInfo: Start = a800, End = abff, Buffer Length = 2048, Type = Pgm, Mask = 00000001
753 1764175250965 GEN4_TO_CONTROLLER_LOG:GEN4_PROGRAM_INT_LOG_PIC24FJ64GA002 Payload End
753 1764175250965 XXXX 1764175250965, Thread 753: XXXX 1764175250965, Entering Thread 753: Commands::runScriptBasic, script name = SetSpeedFromDevice, timeOut = -1 ms  
753 1764175250966 XXXX 1764175250966, Thread 753: XXXX 1764175250966, Exiting Thread 753: Commands::runScriptBasic  
753 1764175250966 XXXX 1764175250966, Thread 753: XXXX 1764175250966, Entering Thread 753: Commands::runScriptBasic with script contents. contents[0] = 0xed, ...  
753 1764175250967 XXXX 1764175250967, Thread 753: XXXX 1764175250967, Exiting Thread 753: Commands::runScriptBasic  
753 1764175250967 XXXX 1764175250967, Thread 753: XXXX 1764175250967, Entering Thread 753: Commands::runScriptBasic with script contents. contents[0] = 0xec, ...  
753 1764175250968 XXXX 1764175250968, Thread 753: XXXX 1764175250968, Exiting Thread 753: Commands::runScriptBasic  
753 1764175250968 XXXX 1764175250968, Thread 753: XXXX 1764175250968, Entering Thread 753: Commands::runScriptBasic, script name = EnterTMOD_LV, timeOut = -1 ms  
753 1764175250996 XXXX 1764175250996, Thread 753: XXXX 1764175250996, Exiting Thread 753: Commands::runScriptBasic  
753 1764175250996 XXXX 1764175250996, Thread 753: XXXX 1764175250996, Entering Thread 753: Commands::runScriptWithUpload, script name = ReadProgmem  
753 1764175250996 XXXX 1764175250996, Thread 753: XXXX 1764175250996, Entering Thread 753: ToolCommUsb::readTransfer, sideData is 0x96 bytes long, transferDataLength is 0x600 bytes long  
753 1764175251121 XXXX 1764175251121, Thread 753: XXXX 1764175251121, Exiting Thread 753: ToolCommUsb::readTransfer,  cr.status = 0x0  
753 1764175251121 XXXX 1764175251121, Thread 753: XXXX 1764175251121, Exiting Thread 753: Commands::runScriptWithUpload  
753 1764175251121 GEN4_TO_CONTROLLER_LOG:GEN4_PROGRAM_INT_LOG_PIC24FJ64GA002 Post:SendOperation
753 1764175251121 GEN4_TO_CONTROLLER_LOG:GEN4_PROGRAM_INT_LOG_PIC24FJ64GA002 Return Value
753 1764175251121 GEN4_TO_CONTROLLER_LOG:GEN4_PROGRAM_INT_LOG_PIC24FJ64GA002 None
753 1764175251121 GEN4_TO_CONTROLLER_LOG:GEN4_PROGRAM_INT_LOG_PIC24FJ64GA002 Return End

753 1764175251122 GEN4_TO_CONTROLLER_LOG:GEN4_PROGRAM_INT_LOG_PIC24FJ64GA002 Pre:SendOperation
753 1764175251122 GEN4_TO_CONTROLLER_LOG:GEN4_PROGRAM_INT_LOG_PIC24FJ64GA002 Payload
753 1764175251122 GEN4_TO_CONTROLLER_LOG:GEN4_PROGRAM_INT_LOG_PIC24FJ64GA002 OperationInfo: Values:
753 1764175251122 GEN4_TO_CONTROLLER_LOG:GEN4_PROGRAM_INT_LOG_PIC24FJ64GA002 OperationInfo: Type = write, Mask = 00000000, Erase = false, Production Mode = true
753 1764175251122 GEN4_TO_CONTROLLER_LOG:GEN4_PROGRAM_INT_LOG_PIC24FJ64GA002 TransferInfo: Start = 0, End = fff, Buffer Length = 8192, Type = Pgm, Mask = 00000000
753 1764175251122 GEN4_TO_CONTROLLER_LOG:GEN4_PROGRAM_INT_LOG_PIC24FJ64GA002 TransferInfo: Start = a800, End = abff, Buffer Length = 2048, Type = Pgm, Mask = 00000001
753 1764175251122 GEN4_TO_CONTROLLER_LOG:GEN4_PROGRAM_INT_LOG_PIC24FJ64GA002 Payload End
753 1764175251123 XXXX 1764175251123, Thread 753: XXXX 1764175251123, Entering Thread 753: Commands::runScriptBasic, script name = EraseTestmemRange, timeOut = 30000 ms  
753 1764175251197 XXXX 1764175251197, Thread 753: XXXX 1764175251197, Exiting Thread 753: Commands::runScriptBasic  
753 1764175251197 XXXX 1764175251197, Thread 753: XXXX 1764175251197, Entering Thread 753: Commands::runScriptWithDownload, script name = WriteProgmem  
753 1764175251397 XXXX 1764175251397, Thread 753: XXXX 1764175251397, Exiting Thread 753: Commands::runScriptWithDownload(WriteProgmem)  
753 1764175251397 XXXX 1764175251397, Thread 753: XXXX 1764175251397, Entering Thread 753: Commands::runScriptWithUpload, script name = ReadProgmem  
753 1764175251397 XXXX 1764175251397, Thread 753: XXXX 1764175251397, Entering Thread 753: ToolCommUsb::readTransfer, sideData is 0x96 bytes long, transferDataLength is 0xc00 bytes long  
753 1764175251640 XXXX 1764175251640, Thread 753: XXXX 1764175251640, Exiting Thread 753: ToolCommUsb::readTransfer,  cr.status = 0x0  
753 1764175251640 XXXX 1764175251640, Thread 753: XXXX 1764175251640, Exiting Thread 753: Commands::runScriptWithUpload  
753 1764175251640 XXXX 1764175251640, Thread 753: XXXX 1764175251640, Entering Thread 753: Commands::runScriptBasic, script name = ExitTMOD, timeOut = -1 ms  
753 1764175251644 XXXX 1764175251644, Thread 753: XXXX 1764175251644, Exiting Thread 753: Commands::runScriptBasic  
753 1764175251644 XXXX 1764175251644, Thread 753: XXXX 1764175251644, Entering Thread 753: Commands::runScriptBasic, script name = SetSpeedFromDevicePE, timeOut = -1 ms  
753 1764175251646 XXXX 1764175251646, Thread 753: XXXX 1764175251646, Exiting Thread 753: Commands::runScriptBasic  
753 1764175251646 XXXX 1764175251646, Thread 753: XXXX 1764175251646, Entering Thread 753: Commands::runScriptBasic with script contents. contents[0] = 0xed, ...  
753 1764175251647 XXXX 1764175251647, Thread 753: XXXX 1764175251647, Exiting Thread 753: Commands::runScriptBasic  
753 1764175251647 XXXX 1764175251647, Thread 753: XXXX 1764175251647, Entering Thread 753: Commands::runScriptBasic with script contents. contents[0] = 0xec, ...  
753 1764175251649 XXXX 1764175251649, Thread 753: XXXX 1764175251649, Exiting Thread 753: Commands::runScriptBasic  
753 1764175251649 XXXX 1764175251649, Thread 753: XXXX 1764175251649, Entering Thread 753: Commands::runScriptBasic, script name = EnterTMOD_PE, timeOut = -1 ms  
753 1764175251677 XXXX 1764175251677, Thread 753: XXXX 1764175251677, Exiting Thread 753: Commands::runScriptBasic  
753 1764175251677 XXXX 1764175251677, Thread 753: XXXX 1764175251677, Entering Thread 753: Commands::runScriptBasic, script name = TestPEConnect, timeOut = 30000 ms  
753 1764175251679 XXXX 1764175251679, Thread 753: XXXX 1764175251679, Exiting Thread 753: Commands::runScriptBasic  
753 1764175251679 XXXX 1764175251679, Thread 753: XXXX 1764175251679, Entering Thread 753: Commands::runScriptWithDownload, script name = WriteProgmemPE  
753 1764175251883 XXXX 1764175251883, Thread 753: XXXX 1764175251883, Exiting Thread 753: Commands::runScriptWithDownload(WriteProgmemPE)  
753 1764175251883 XXXX 1764175251883, Thread 753: XXXX 1764175251883, Entering Thread 753: Commands::runScriptBasic, script name = CalcCRC_PE, timeOut = -1 ms  
753 1764175251923 XXXX 1764175251923, Thread 753: XXXX 1764175251923, Exiting Thread 753: Commands::runScriptBasic  
753 1764175251924 XXXX 1764175251924, Thread 753: XXXX 1764175251924, Entering Thread 753: Commands::runScriptBasic, script name = ExitTMOD, timeOut = -1 ms  
753 1764175251927 XXXX 1764175251927, Thread 753: XXXX 1764175251927, Exiting Thread 753: Commands::runScriptBasic  
753 1764175251927 XXXX 1764175251927, Thread 753: XXXX 1764175251927, Entering Thread 753: Commands::runScriptBasic, script name = SetSpeedFromDevice, timeOut = -1 ms  
753 1764175251929 XXXX 1764175251929, Thread 753: XXXX 1764175251929, Exiting Thread 753: Commands::runScriptBasic  
753 1764175251929 XXXX 1764175251929, Thread 753: XXXX 1764175251929, Entering Thread 753: Commands::runScriptBasic with script contents. contents[0] = 0xed, ...  
753 1764175251929 XXXX 1764175251929, Thread 753: XXXX 1764175251929, Exiting Thread 753: Commands::runScriptBasic  
753 1764175251929 XXXX 1764175251929, Thread 753: XXXX 1764175251929, Entering Thread 753: Commands::runScriptBasic with script contents. contents[0] = 0xec, ...  
753 1764175251930 XXXX 1764175251930, Thread 753: XXXX 1764175251930, Exiting Thread 753: Commands::runScriptBasic  
753 1764175251930 XXXX 1764175251930, Thread 753: XXXX 1764175251930, Entering Thread 753: Commands::runScriptBasic, script name = EnterTMOD_LV, timeOut = -1 ms  
753 1764175251933 XXXX 1764175251933, Thread 753: com.Send returned false 
753 1764175251934 XXXX 1764175251934, Thread 753: transfer: exception after writeHeaderAndGetResult null 
753 1764175251935 XXXX 1764175251935, Thread 753: XXXX 1764175251935, Entering Thread 753: ToolCommUsb::recoverFromProtocolError, type = NO_SCRIPT  
753 1764175251935 XXXX 1764175251935, Thread 753: Send Abort Script Engine Command 
753 1764175251935 XXXX 1764175251935, Thread 753: XXXX 1764175251935, Entering Thread 753: ToolCommUsb::killScriptEngine  
753 1764175261936 XXXX 1764175261936, Thread 753: com.Send returned false 
753 1764175261936 XXXX 1764175261936, Thread 753: Failed sending Abort Script Engine Command. Set nuclear option = true 
753 1764175261936 XXXX 1764175261936, Thread 753: About to nuke 
753 1764175261936 XXXX 1764175261936, Thread 753: XXXX 1764175261936, Entering Thread 753: ToolCommUsb::nuclearOption  
753 1764175271938 XXXX 1764175271938, Thread 753: com.Send returned false

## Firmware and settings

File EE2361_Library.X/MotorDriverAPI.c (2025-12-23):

#include <xc.h>
#include <stdint.h>
#include <stdbool.h>

#include "blommel_lab2b_asmLib_v1.h"

#define FCY 8000000UL
#include <libpic30.h>
//
//#pragma config FNOSC = PRI
//#pragma config POSCMOD = XT
//#pragma config FCKSM = CSDCMD
//#pragma config FWDTEN = OFF
//#pragma config JTAGEN = OFF

#define DIR_TRIS   TRISAbits.TRISA1
#define DIR_LAT    LATAbits.LATA1
#define PWM_TRIS   TRISBbits.TRISB2

static void delay(int nDelay) {
    for (int i = 0; i < nDelay; ++i ) {
        oneMilliSecond();
    }
}

static void pwm_init(void){
    T2CON = 0; TMR2 = 0;
    PR2 = 399;
    T2CONbits.TCKPS = 0b00;
    T2CONbits.TON = 1;

    OC1CON = 0;
    OC1R = 0; OC1RS = 0;
    OC1CONbits.OCTSEL = 0;  
    OC1CONbits.OCM = 0b110;

    PWM_TRIS = 0;
}

static void pps_init(void){
    __builtin_write_OSCCONL(OSCCON & 0xBF);
    RPOR1bits.RP2R = 18;
    __builtin_write_OSCCONL(OSCCON | 0x40);
}

static void pwm_set_duty(uint16_t duty){
    if (duty > PR2) duty = PR2;
    OC1RS = duty;
}

void motor_init(void){
    /*
     Arguments: void
Function: This function initializes both the peripherals and the motor driver 
     * that is used within the motor driver code.
Return: Void
*/
    DIR_TRIS = 0; DIR_LAT = 0;
    pps_init();
    pwm_init();
}

void motor_set_direction(uint8_t dir){
    /*
     Arguments: dir
Function: This function allows us to choose the direction that the motor 
     * driver can spin. This is either a forward or backward direction
     *  corresponding to either a value of 0 or 1.
Return: Void

     */
    DIR_LAT = (dir ? 1 : 0);
}

void motor_set_speed_percent(uint8_t speed){
    /*
     Arguments: uint8_t speed
Function: This function allows us to choose any percentage of the max rpm we 
     * want to use on the motor driver. It then converts the percentage into a
     *  usable duty cycle value.
Return: Void
*/
    if (speed > 100) speed = 100;
    uint16_t duty = (uint16_t)((speed * PR2) / 100);
    pwm_set_duty(duty);
}

//int main(void){
//    motor_init();
//
//    while(1)
//    {
//        // Forward, high speed
//        motor_set_direction(1);
//        motor_set_speed_percent(80);
//        delay(2000);
//
//        // Forward, medium speed
//        motor_set_speed_percent(50);
//        delay(2000);
//
//        // Forward, low speed
//        motor_set_speed_percent(20);
//        delay(2000);
//
//        // Stop
//        motor_set_speed_percent(0);
//        delay(1000);
//
//        // Reverse, low speed
//        motor_set_direction(0);
//        motor_set_speed_percent(20);
//        delay(2000);
//
//        // Reverse, medium speed
//        motor_set_speed_percent(50);
//        delay(2000);
//
//        // Reverse, high speed
//        motor_set_speed_percent(80);
//        delay(2000);
//
//        // Stop
//        motor_set_speed_percent(0);
//        delay(1000);
//    }
//
//    return 0;
//}

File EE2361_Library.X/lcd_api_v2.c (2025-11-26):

//#include "lcd.h"

#include <xc.h>
#define FCY 16000000UL
//#include "blommel_lab4_asmLib_v1.h"
#include <libpic30.h>
#include "lcd_api_v2.h"




#define FUNCTIONSET_2LINE   0x38
#define ENTRY_MODE_INC      0x06
#define DISPLAY_ON          0x0C
#define CLEAR_DISPLAY       0x01

#define BAUD_RATE       0x009D
#define COMMAND         0b00000000
#define DATA            0b01000000

#define LCDaddy         0x3C
#define LCDaddy_writ    (LCDaddy << 1) & 0b11111110
#define LCDaddy_read    (LCDaddy << 1) | 0b00000001

#define LCD_COLS        10


void lcd_init(){
    /*Goal: To initialize the DOGS104-A LCD. It sets up the 
     * I2C pins, and initializes the I2C connection.
     * This function also handles the initialization and formatting
     * of the LCD display, such as setting the font size,
     * power control, and contrast
     * 
     * Parameters: void
     * 
     * Return: void
     */
    
    TRISBbits.TRISB8 = 1;   //SCL1
    TRISBbits.TRISB9 = 1;   //SDA1
    
    //reset pin as output and pulse
    TRISBbits.TRISB6 = 0;
    __delay_ms(1);
    
    LATBbits.LATB6 = 0;
    __delay_ms(10);
    LATBbits.LATB6 = 1;
    __delay_ms(10);
    
    
    //config i2c
    I2C1CONbits.I2CEN = 0;
    
    I2C1BRG = BAUD_RATE;
    I2C1CONbits.DISSLW = 1;
    _MI2C1IF = 0;
    _MI2C1IE = 0;
    
    I2C1CONbits.I2CEN = 1;

    lcd_cmd(0x3A);  //function set
    lcd_cmd(0x09);  //extended function set 4-line mode
    lcd_cmd(0x06);  //entry mode (0x05 for top view)
    lcd_cmd(0x1E);  //bias setting
    lcd_cmd(0x39);  // function set (re=0 is=1)
    lcd_cmd(0x1B);  // internal OSC frequency
    lcd_cmd(0x6E);  //follower control
    lcd_cmd(0x56);  //power control, contrast high bits =c5:c4
    lcd_cmd(0x7A);  // contrast low bits
    lcd_cmd(0x38);  //function set (re=0, is=0) normal
    lcd_cmd(0x0c);  //display on, cursor+blink=0x0F 
    lcd_cmd(0x01);  //clear display
    lcd_cmd(0x3a);  //function set
    lcd_cmd(0x09);  //extended function set 4-line mode
    lcd_cmd(0x1a);  // bias 
    lcd_cmd(0x3c);  //finalize setup
    
    __delay_ms(2);
}


void conditionStart(){
    /*start sending an i2c command
     */
    I2C1CONbits.SEN = 1;
    while (I2C1CONbits.SEN);
}

void conditionStop(){
    /*end i2c communciation
     */
    I2C1CONbits.PEN = 1;
    while (I2C1CONbits.PEN);
}

int shouldWaitForSending(){
    // return 1 if should wait, 0 if should stop waiting
    return (_MI2C1IF != 1) || (I2C1STATbits.TRSTAT == 1);
}

void blockSendByte(char message){
    /*blocking, send a byte thorugh i2c
     */
    _MI2C1IF = 0;
    I2C1TRN = message;
    while(shouldWaitForSending());
}

void lcd_cmd(char arg){
    /*  Goal: to send one full I2C command message. This includes
     * a start sequence, address, command, the data, and
     * a stop sequance
     * 
     *  Parameters: char args = the message
     * in the data byte to be sent to the lcd
     * 
     *  Return: void
     */
    conditionStart();
    
    blockSendByte(LCDaddy_writ);
    blockSendByte(COMMAND);
    blockSendByte(arg);
    
    conditionStop();
}


void lcd_printChar(char character){
    /*  Goal: to send one full I2C message holding 
     * a data byte for the lcd. This includes
     * a start sequence, address, command, the data, and
     * a stop sequance
     * 
     *  Parameters: char character = the character
     * sent to and displayed by the lcd
     * 
     *  Return: void
     */
    conditionStart();
    
    blockSendByte(LCDaddy_writ);
    blockSendByte(DATA);
    blockSendByte(character);
    
    conditionStop();
    
}


void lcd_setCursor(char x, char y){
    /*  Goal: to change the location of the cursor. This
     * will calculate what the data byte should be based
     * on the x and y positions determined by the
     * arguments, and will send that to the lcd
     * 
     *  Parameters:
     *  char x = the x position the cursor should move to.
     * This is 0 indexed so it starts counting at 0
     *  char y = the y position the cursor should move to.
     * This is 0 indexed so it starts counting at 0
     * 
     *  Return: void
     */
    
    char position = 0x00;
    
    if (y == 0x01){
        position = 0x20;
    }
    
    position += x;
    
    position |= 0b10000000;
    
    char controlByte = 0x00;
    
    conditionStart();
    
    blockSendByte(LCDaddy_writ);
    blockSendByte(controlByte);
    blockSendByte(position);
    
    conditionStop();
}

int _str_len(const char *s) {
    if (!s) return 0;
    int n = 0;
    while (s[n] != '\0') n++;
    return n;
}


void print_window(const char *str, int start) {
    int i;
    const char *p = str;
    
    int skip = start;
    while (skip > 0 && *p != '\0') {
        p++;
        skip--;
    }

    
    for (i = 0; i < LCD_COLS; i++) {
        if (*p == '\0') {
            lcd_printChar(' '); 
        } else {
            lcd_printChar(*p);
            p++;
        }
    }
}



void lcd_printStr(const char *str, int delay_ms, char row) {
    /*  Goal: to create an animated display that cycles throug
     * all charcters in a string. This should look like a 
     * string of characters moving across the screen like a 
     * moving display. This is a blocking function, so
     * no other function can run without interrupting this one
     * 
     *  Parameters:
     *  const char *str = the pointer to an "array" of 
     * characters the user wishes to be sent to the lcd
     * for an animated/moving display
     *  int delay_ms = the time in milliseconds between
     * frames of the display
     *  char row = the rown number the user wishes the string
     * to be displayed on. 
     * 
     *  Return: void
     * 
     */
    
    
    int len = _str_len(str);
    int offset = 0;
    
    while (offset <= len) {
        
        
        lcd_setCursor(0, row);
        print_window(str, offset);
        
        offset++;

        __delay_ms(delay_ms);
    }
}

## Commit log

2025-11-20 Add temporary working IR frame and motor
2025-11-26 Working RPM counter combined with the LED display. A bit janky with capturing new inputs after buffer is filled tho
2025-12-09 Add schematic and Solidworks files
    [EE_2361_fan_holder.SLDPRT, EE_2361_pillar.SLDPRT, EE_2361_pillar_cap.SLDPRT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]
